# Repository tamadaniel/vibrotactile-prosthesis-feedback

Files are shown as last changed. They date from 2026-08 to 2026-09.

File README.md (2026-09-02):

# Vibrotactile Feedback Device for Transfemoral Prostheses

Open design files for a **low-cost, fully analog vibrotactile feedback add-on** for transfemoral (above-knee) prostheses. A force-sensing resistor under the heel of the prosthetic foot switches a coin vibration motor mounted on the prosthetic tube, signaling foot–ground contact to the user at every step. The device clamps onto existing prostheses — **no structural modification, no software, no microcontroller**.

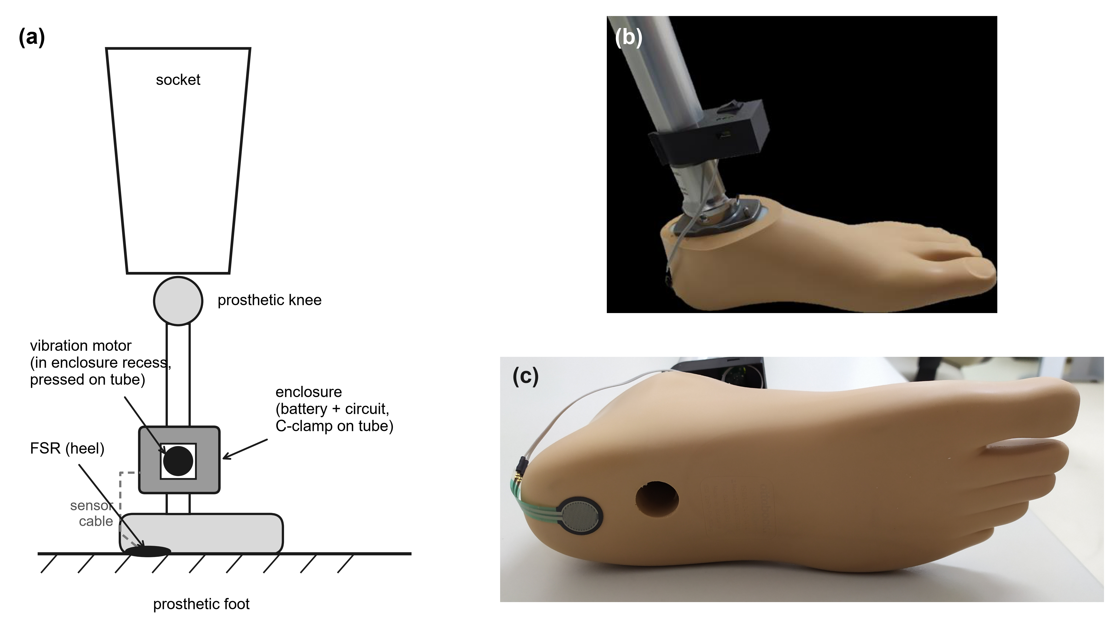
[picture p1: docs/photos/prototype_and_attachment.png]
Prototype and attachment


## How it works

Loading the heel-mounted force-sensing resistor (FSR) above an adjustable threshold drives a small-signal NPN transistor into saturation, switching the coin motor on for the loading and mid-stance period of the prosthetic limb.

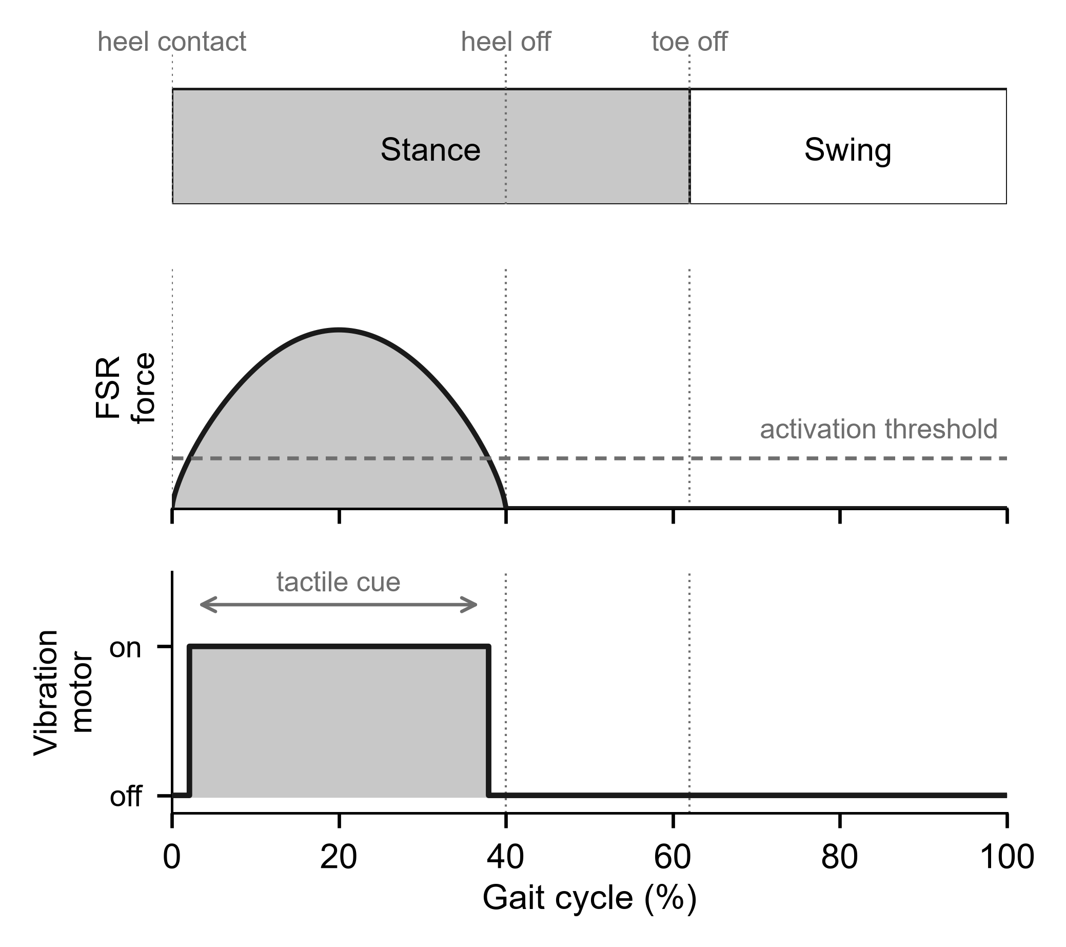
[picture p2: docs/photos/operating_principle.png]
Operating principle


Circuit (as used in the user study; reconstructed from the design files):

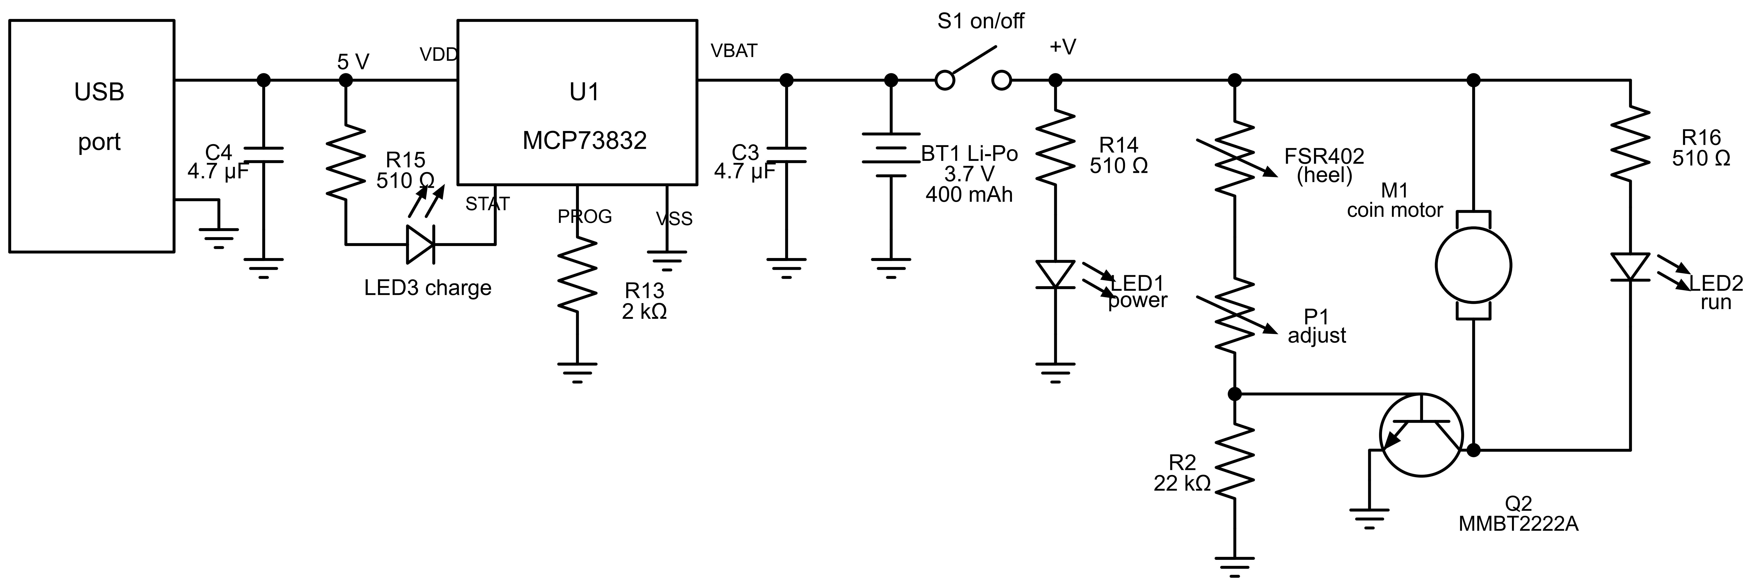
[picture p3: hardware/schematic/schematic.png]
Schematic


- **Charging:** MCP73832 constant-current/constant-voltage controller, 500 mA (set by the 2 kΩ program resistor), USB input.
- **Power:** single Li-Po cell, 3.7 V / 400 mAh; on/off switch on the battery rail; ≈50 mA total draw → ≈8 h continuous use.
- **Sensing/actuation:** FSR402 (heel) in series with an adjustment potentiometer (P1) against a fixed 22 kΩ pulldown, driving an MMBT2222A that switches the coin-type ERM motor (10 mm × 3 mm, ~150 Hz nominal). Turning P1 raises the activation threshold and can attenuate the vibration.
- **Indicators:** charge (LED3), power-on (LED1), motor activity (LED2).

## Repository contents

| Path | Contents |
|---|---|
| `hardware/pcb/` | Gerber fabrication files, BOM (with LCSC part numbers), pick-and-place, netlist, PCB layout PDF, 3D STEP of the board, EasyEDA Pro project |
| `hardware/schematic/` | Clean schematic (PNG) |
| `enclosure/` | 3D-printable housing and lid (STL + SolidWorks), K1 Max G-code, print settings |
| `bench/latency/` | Oscilloscope captures, analysis code and figure for the FSR-to-vibration delay |
| `docs/photos/` | Prototype photos, block diagram, operating principle |

## Cost

Quoted at a mainstream turnkey PCB assembly service (JLCPCB, Aug. 2026), batch of **5 assembled boards**:

| Item | 5-board batch | Per board |
|---|---|---|
| Components (9 line items) | US$ 7.10 | **< US$ 1.50** |
| PCB fabrication | US$ 4.00 | US$ 0.80 |
| Assembly, setup, stencil, fees | US$ 28.52 (incl. components) | — |
| **Total (PCB + assembly)** | **US$ 32.52** | **≈ US$ 6.50** |

Setup fees dominate at this batch size; the per-unit cost approaches the component cost at volume. Off-board parts (FSR402 sensor, coin motor, battery, switch, potentiometer, wiring) and the 3D-printed enclosure are not included in the quote. The charge-management IC (MCP73832) accounts for most of the component cost.

## Building one

1. **PCB:** upload `hardware/pcb/Gerber_*.zip`, the BOM, and the pick-and-place file to a turnkey assembly service (e.g., JLCPCB), or fabricate the board and hand-solder — all parts are mass-market components.
2. **Off-board parts:** FSR402 force-sensing resistor, C1026B-class coin ERM motor (10 × 3 mm), 3.7 V/400 mAh Li-Po cell (602525 or similar), slide switch, small potentiometer, hook-up wire.
3. **Enclosure:** print the housing and lid from `enclosure/` (PLA, 0.20 mm layers, 15% infill, no supports; ~29 min, ~14 g); the C-clamp fits the prosthetic tube by interference — no tools or screws.
4. **Mounting:** fix the FSR to the plantar surface of the prosthetic foot at the heel region (thin adhesive tape); clamp the enclosure to the distal portion of the prosthetic tube — the coin motor, seated in the enclosure recess, is pressed against the tube automatically; route the sensor cable along the prosthesis.
5. **Setup:** switch on, confirm the wearer perceives the vibration at the residual limb/socket interface, and adjust P1 so the motor activates on weight bearing at a comfortable intensity.

## Status and evidence

This is a **research prototype**. In a bench test referenced to ISO 2631-1, the vibration transmitted to the socket region measured 0.48 ± 0.06 m/s², and the delay from foot loading to vibration onset was 110 ms (95% CI 103–117 ms), reaching half amplitude at 137 ms (raw captures and analysis in [`bench/latency/`](bench/latency/)). In a cross-sectional study at IMREA HC-FMUSP (research ethics approval CAAE 75258523.9.0000.0068), ten experienced transfemoral prosthesis users wore the device during a supervised ~5-min walk: all perceived the stimulus, no device-related adverse events occurred, and all eight B-QUEST 2.0 device items reached a median score of 5/5. **No clinical outcome (gait, balance, proprioception) has been evaluated yet**; a controlled study with three-dimensional gait analysis is planned.

A preliminary account of the device concept and bench measurements appeared in:

> Tamashiro, D.S.U., Coelho, D.B., Battistella, L.R. (2025). *Development of a Proprioceptive Stimulation Device to Gait in Transfemoral Amputees.* In: XXIX Brazilian Congress on Biomedical Engineering (CBEB 2024), IFMBE Proceedings, vol. 125. Springer, Cham. https://doi.org/10.1007/978-3-031-93646-3_1

A full journal manuscript (complete technical description, bench characterization, and the user satisfaction study) is under preparation/submission; this repository accompanies it.

## Known limitations of this board revision

Review these before building or deriving from this design:

1. **USB-C CC pulldowns are absent.** Only VBUS (A9/B9) and GND (A12/B12) are connected; CC1/CC2 float and there are no 5.1 kΩ pulldowns. Consequence: the board charges normally from a USB-A→USB-C cable, but **will not receive power from USB-C→USB-C cables or USB-C (PD) chargers**. Next revision: add two 5.1 kΩ 0402 resistors, CC1→GND and CC2→GND.
2. **Charge current is 1.25C for the specified cell.** R13 = 2 kΩ programs the MCP73832 to 500 mA, above the standard 1C rating of the 400 mAh cell. Next revision: R13 = 3.3 kΩ (≈300 mA, ≈0.75C) — or keep 2 kΩ only with cells ≥500 mAh. Use only protected Li-Po cells.
3. **No flyback diode across the motor.** The inductive kick of the ERM motor at every turn-off stresses Q2 (adequate margin in practice, but repeated at every step). Next revision: a small Schottky or 1N4148 across the motor terminals.
4. **Motor overdrive.** The motor drive rail (3.7–4.2 V) slightly exceeds the motor's rated voltage (2.7–3.3 V); P1 can compensate by limiting base drive.
5. **Component availability.** The yellow 0603 LEDs (LED1/LED2) were low-stock at quoting time; any 0603 indicator LED substitutes directly. Choosing basic-library alternatives for the extended parts (headers, USB connector, LEDs) reduces the assembly fee.

## Disclaimer

This design is provided for **research and educational purposes**. It is **not an approved medical device** and must not be used for clinical decision-making or unsupervised patient care. Any use with patients must be conducted under appropriate ethical approval and professional supervision.

## License

Released under **CC BY 4.0** (see `LICENSE`). You may use, modify, and redistribute, with attribution — please cite the CBEB chapter above (see `CITATION.cff`).

## Authors

Daniel Seiei Uehara Tamashiro¹·², Gustavo Shimabukuro Marchini², Daniel Boari Coelho¹, Linamara Rizzo Battistella²
¹ Biomedical Engineering, Universidade Federal do ABC (UFABC), Brazil · ² Instituto de Medicina Física e Reabilitação, HCFMUSP, Universidade de São Paulo, Brazil

Contact: daniel.tamashiro@hc.fm.usp.br

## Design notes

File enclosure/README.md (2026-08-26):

# Enclosure (3D-printable)

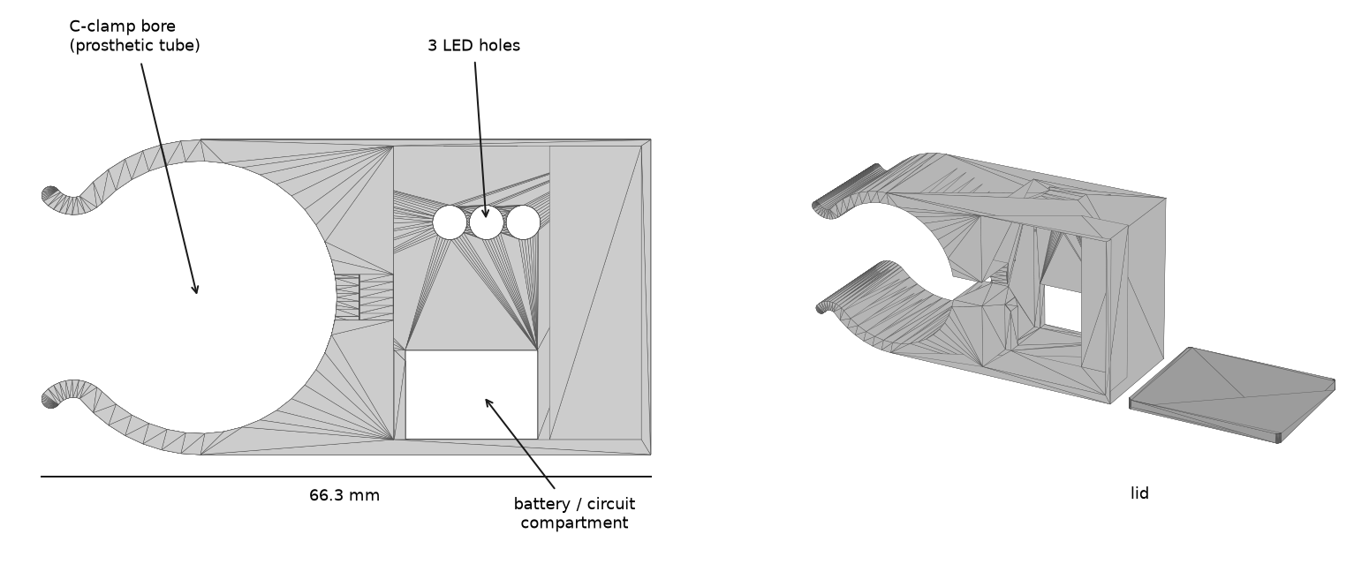
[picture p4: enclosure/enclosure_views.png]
Enclosure views


Two-part 3D-printable housing that holds the battery, the circuit board and the vibration motor, and clamps onto the distal prosthetic tube. The force-sensing resistor is **not** inside the enclosure: it is attached to the plantar surface of the prosthetic foot at the heel and connected by a thin cable.

Three features make the assembly tool-free:

- **C-shaped clamp** — snaps onto the tube by interference fit; no screws, no structural modification of the prosthesis.
- **Motor recess** — the coin motor seats in a recess facing the tube, so closing the clamp automatically presses the motor against the prosthesis. There is no separate motor mounting step, and the vibration is injected directly into the prosthesis structure.
- **Three ⌀3.75 mm holes (4 mm pitch)** on the outer face, so discrete through-hole indicator LEDs can be soldered to sit flush with the surface: charging, power-on, and motor activity stay visible with the device closed.

## Files

| File | Description |
|---|---|
| `enclosure_housing.stl` / `.SLDPRT` | main body: clamp, motor recess, LED holes, battery/circuit compartment |
| `enclosure_lid.stl` / `.SLDPRT` | closing lid |
| `gcode/housing+lid_K1Max_0.4_PLA.gcode` | both parts, ready to print on a Creality K1 Max |

## Measured dimensions (from the meshes)

| Feature | Value |
|---|---|
| Housing envelope | 66.3 × 23.0 × 34.3 mm |
| Lid | 31.8 × 26.6 × 1.9 mm |
| C-clamp bore | ⌀ ≈ 33.6 mm |
| LED holes | 3 × ⌀3.75 mm, 4 mm pitch |
| Outer face thickness at the LED holes | ≈ 2 mm |
| Filament for both parts | 4.73 m ≈ 14 g (incl. brim) |
| Tube-mounted unit (enclosure + lid + battery + circuit + motor) | 25 g |

## Print settings

Generated with Creality Print 4.3.7 for a **Creality K1 Max**, 0.4 mm nozzle:

| Parameter | Value |
|---|---|
| Filament | Generic PLA, 1.75 mm |
| Nozzle / bed temperature | 230 °C / 45 °C |
| Layer height | 0.20 mm |
| Wall line count | 2 (≈0.87 mm) |
| Top / bottom layers | 4 / 4 |
| Infill | grid, 15 % (line distance 6 mm) |
| Supports | not required |
| Bed adhesion | auto brim |
| Print speed | 250 mm/s (outer wall 210) |
| Flow ratio | 95 % |
| Both parts | ≈29 min |

Z-seam is set to *sharpest corner / hide seam*. PETG also prints this geometry (≈250 °C / 80 °C) and is the tougher option for the clamp arms, which flex on every installation.

## Printing notes

The clamp relies on the elasticity of the print for its interference fit, so orient the part such that layer lines do not run perpendicular to the clamp arms — otherwise the arms tend to delaminate when snapped onto the tube. Verify the bore against the tube you are targeting before printing a batch (the modular standard is 30 mm; the bore in this model is larger and was matched to the tube used in our prototype), and adjust the diameter in the SolidWorks part if needed.

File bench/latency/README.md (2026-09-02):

# Latency measurement: foot loading to vibration

How long the device takes to respond, from the moment the FSR is loaded to the
moment the motor is actually vibrating. This folder holds the raw oscilloscope
captures, the analysis code, and a script that reproduces the two numbers
reported in the paper.

## Result

| Instant | Definition | Mean (n = 5) | 95% CI |
|---|---|---|---|
| Onset | first sustained excursion beyond 5 SD of the pre-contact noise | 110 ms | 103–117 ms |
| Half amplitude | envelope reaches half of its steady-state value | 137 ms | 132–142 ms |

Two instants are reported because the eccentric-mass motor accelerates
progressively: the vibration builds up over tens of milliseconds instead of
starting abruptly, so any single number depends on the threshold chosen.
`tempos_criterio.pdf` makes that dependence visible — it plots the piezo
envelope for all five captures with the 3, 5 and 10 σ criteria marked, and the
three land at visibly different points on the same rise.

Almost all of this delay is mechanical, not electronic. The analog circuit
switches the motor within microseconds; the rest is the motor spinning up.
Shortening it would require a faster actuator, such as a linear resonant
actuator, not a redesign of the circuit.

## Setup

Two-channel oscilloscope (PicoScope 2204A, 6.1 kHz per channel) recording
simultaneously:

- **Channel A** — the FSR, which steps from about 3.75 V to about 3.02 V when
  loaded.
- **Channel B** — a piezoelectric element on the motor housing, picking up the
  vibration itself rather than the drive signal.

## Two corrections the raw cursor readings do not make

The manual cursor readings in `tempo.xlsx` (mean 93.8 ms over 10 trials)
**understate** the delay, for two reasons that the analysis code handles:

1. **The oscilloscope trigger is not the FSR step.** The scope fired 2.2 to
   6.8 ms *after* the step had already begun, so taking t = 0 as the start
   loses those milliseconds. `degrau_fsr()` locates the real step by its
   mid-level crossing, which is immune both to the transition spreading across
   two or three samples and to noise spikes of up to 0.18 V.
2. **The piezo has no clean edge.** Its amplitude grows slowly, so the instant
   read off the screen depends entirely on where the eye places the threshold.
   The code reports several thresholds instead of one, so the sensitivity is
   visible rather than hidden.

All timing here is therefore referenced to the FSR step itself, not to the
oscilloscope trigger.

## Data

Ten captures were taken. **Five contain complete waveforms** (`med3`, `med7`,
`med8`, `med9`, `med10`) and are the five kept here and analysed; the other
five held only acquisition metadata, with no waveform to measure, and are not
included.

- `*_med*.csv` — raw captures, semicolon-separated, comma decimal, latin-1.
  Columns: time (ms), channel A (V), channel B (mV).
- `*_med*.png` — PicoScope screenshots of the same captures.
- `tempo.xlsx` still lists all ten trials, since the manual cursor readings
  were taken on screen before the discard.

## Code

Requires `numpy`, `pandas`, `scipy`, `matplotlib`, `openpyxl`.

```bash
python reproduce_paper_values.py   # the two numbers in the paper, with CIs
python analisa_tempos.py           # full per-trial table, 3/5/10 sigma
python figura_tempos.py            # regenerates tempos_criterio.pdf/.png
```

`reproduce_paper_values.py` is the entry point if you only want to check the
published values. `analisa_tempos.py` is the original analysis, kept verbatim
except that its report was moved inside a `__main__` guard so it can be
imported quietly; its comments are in Portuguese. The half-amplitude instant is
computed in `reproduce_paper_values.py`, which states its envelope definition
explicitly, since that number depends on it.

## Limitation

Five valid captures is a small sample, and the measurement was made on the
bench with the FSR pressed by hand, not under a walking load. Absolute timing
under gait may differ.

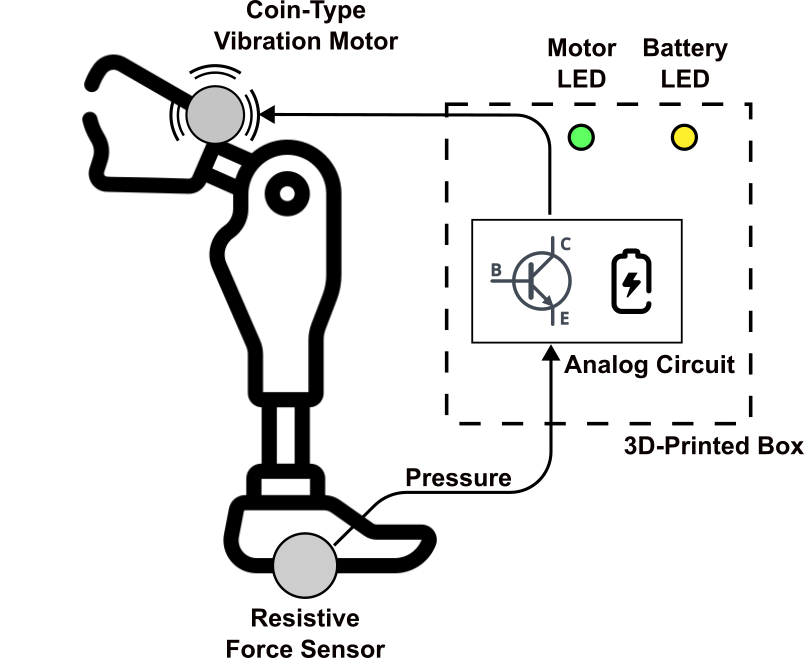
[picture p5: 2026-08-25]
docs/photos/block_diagram.png

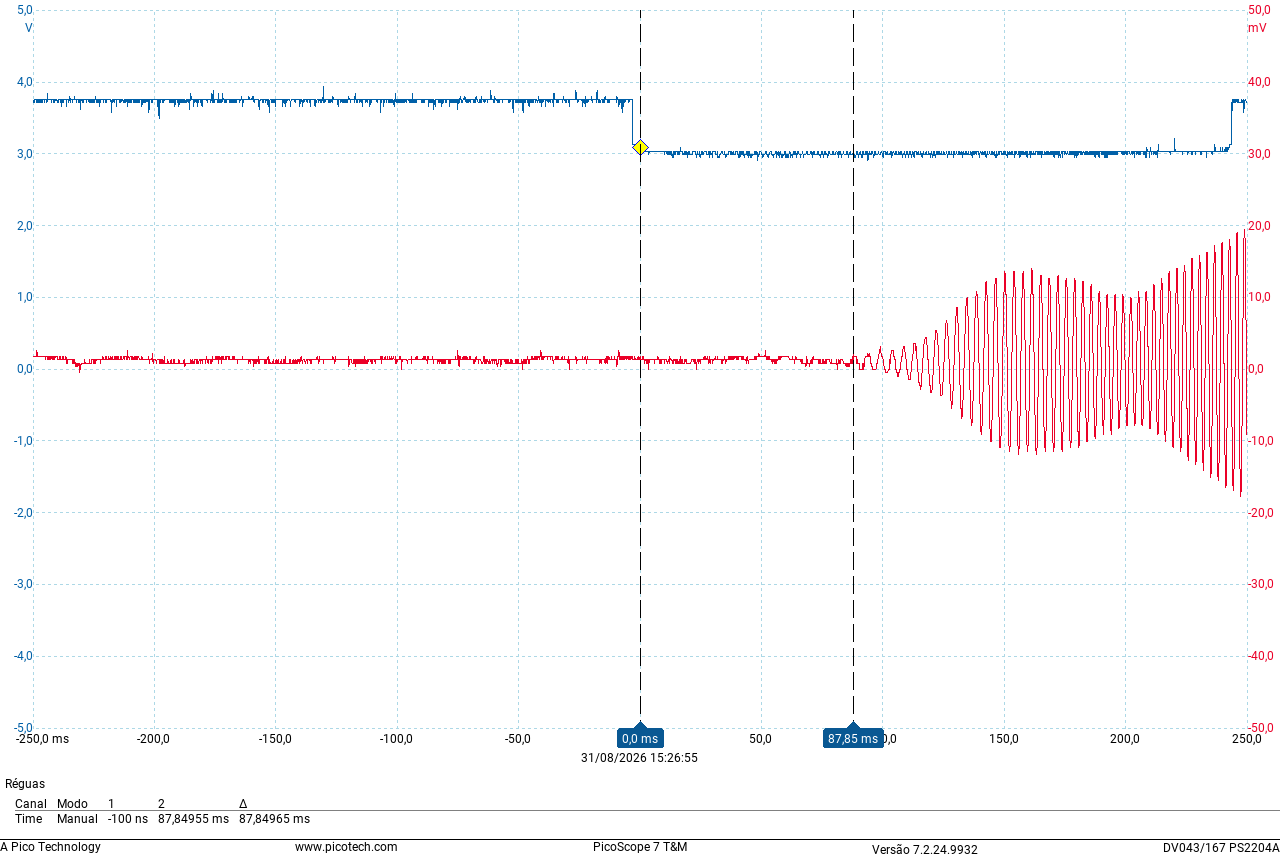
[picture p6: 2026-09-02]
bench/latency/20260831-0002_joelho-0002_med3.png

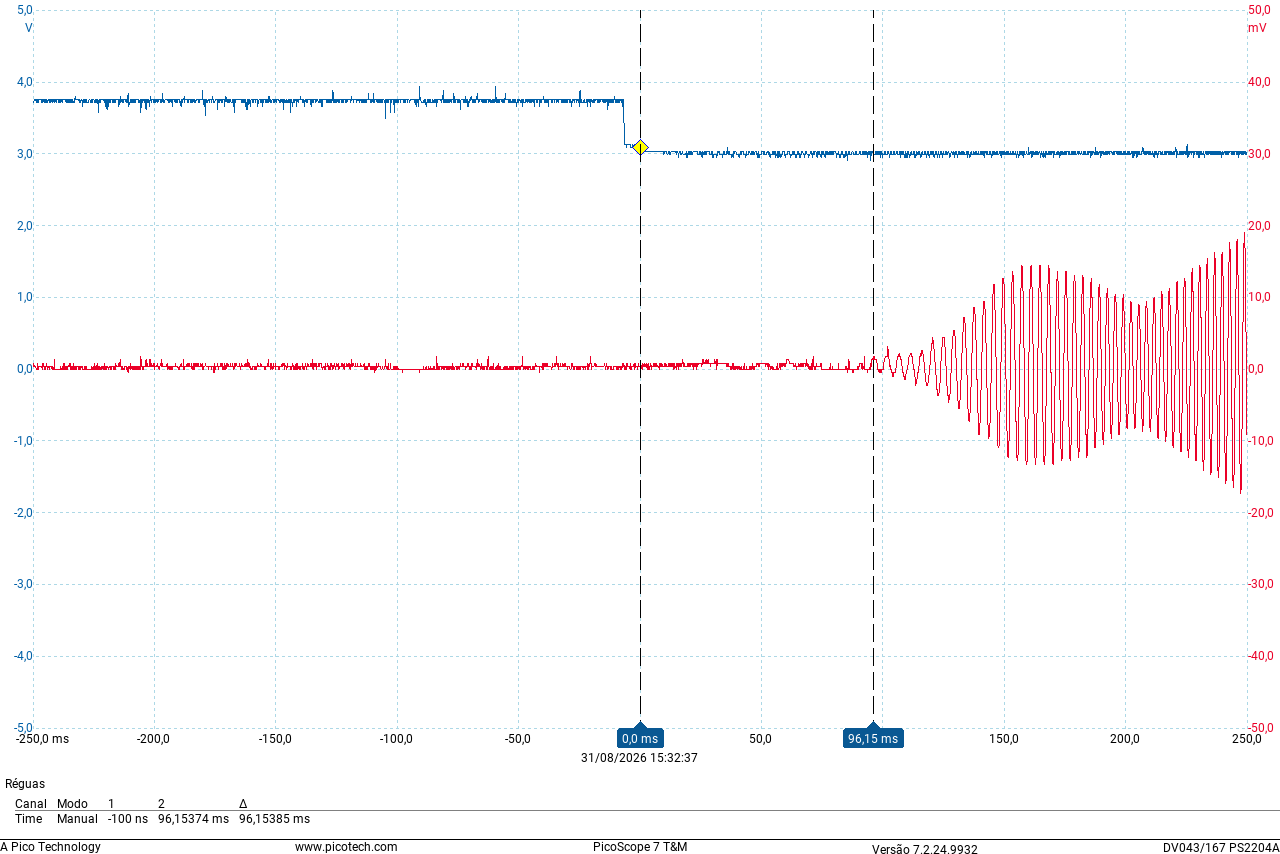
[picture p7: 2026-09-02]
bench/latency/20260831-0002_joelho-0002_med7.png

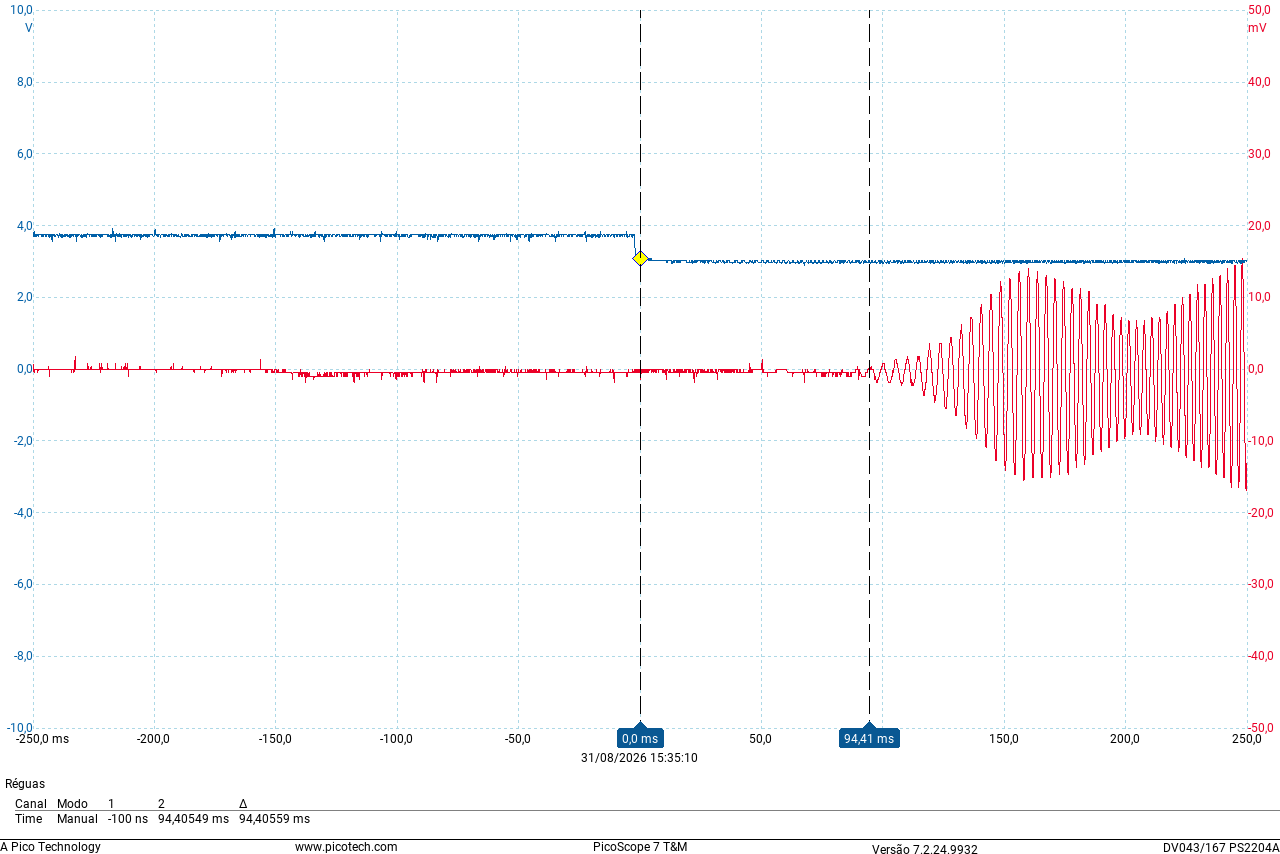
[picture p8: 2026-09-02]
bench/latency/20260831-0002_joelho-0002_med10.png

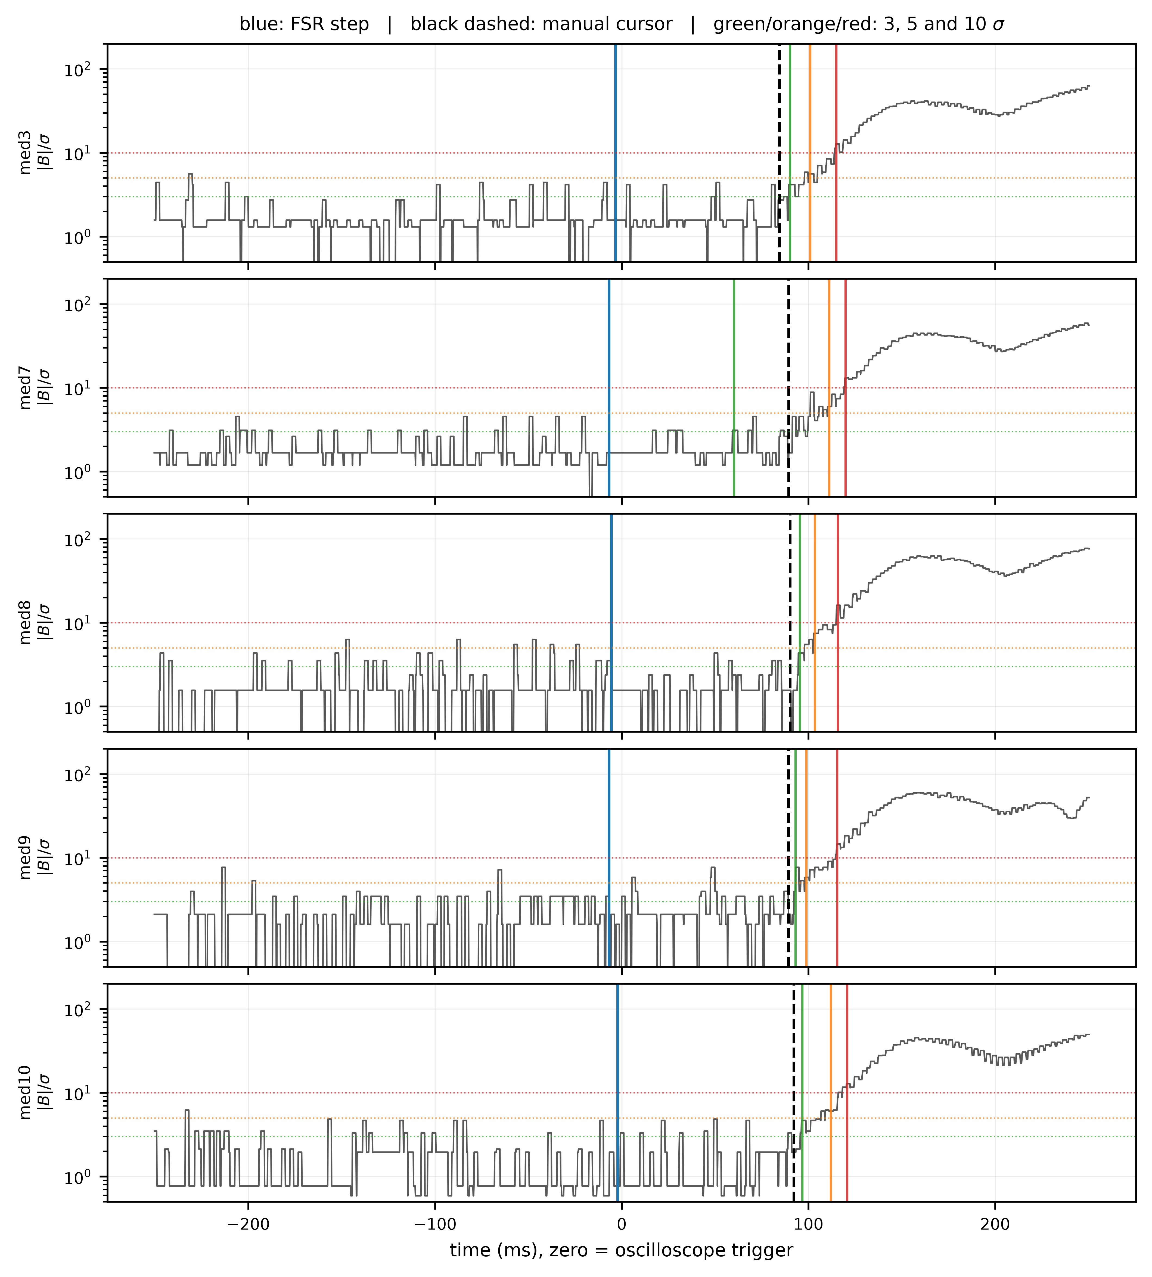
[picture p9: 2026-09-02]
bench/latency/tempos_criterio.png

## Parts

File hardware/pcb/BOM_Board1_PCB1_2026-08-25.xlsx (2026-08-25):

No. | Quantity | Comment | Designator | Footprint | Value | Manufacturer Part | Manufacturer | Supplier Part | Supplier
1 | 2 | 4.7uF | C3,C4 | C0402 | 4.7uF | CL05A475MP5NRNC | SAMSUNG(三星) | C23733 | LCSC
2 | 5 | PZ254V-11-02P | H1,H2,H3,H4,H5 | HDR-TH_2P-P2.54-V-M |  | PZ254V-11-02P | XFCN(兴飞) | C492401 | LCSC
3 | 2 | 19-213/Y2C-CQ2R2L/3T(CY) | LED1,LED2 | LED0603-RD-YELLOW |  | 19-213/Y2C-CQ2R2L/3T(CY) | EVERLIGHT(亿光) | C72038 | LCSC
4 | 1 | KT-0603R | LED3 | LED0603-RD |  | KT-0603R | KENTO | C2286 | LCSC
5 | 1 | MMBT2222A 1P | Q2 | SOT-23-3_L2.9-W1.3-P1.90-LS2.4-BR |  | MMBT2222A 1P | CJ(江苏长电/长晶) | C8512 | LCSC
6 | 1 | 22kΩ | R2 | R0402 | 22kΩ | 0402WGF2202TCE | UNI-ROYAL(厚声) | C25768 | LCSC
7 | 1 | 2kΩ | R13 | R0402 | 2kΩ | 0402WGF2001TCE | UNI-ROYAL(厚声) | C4109 | LCSC
8 | 3 | 510Ω | R14,R15,R16 | R0402 | 510Ω | 0402WGF5100TCE | UNI-ROYAL(厚声) | C25123 | LCSC
9 | 1 | MCP73832T-2DCI/OT | U1 | SOT-23-5_L2.9-W1.6-P0.95-LS2.8-BR |  | MCP73832T-2DCI/OT | MICROCHIP(美国微芯) | C625601 | LCSC
10 | 1 | TYPE-C 6P | USB1 | TYPE-C-SMD_TYPE-C-6P |  | TYPE-C 6P | SHOU HAN(首韩) | C456012 | LCSC

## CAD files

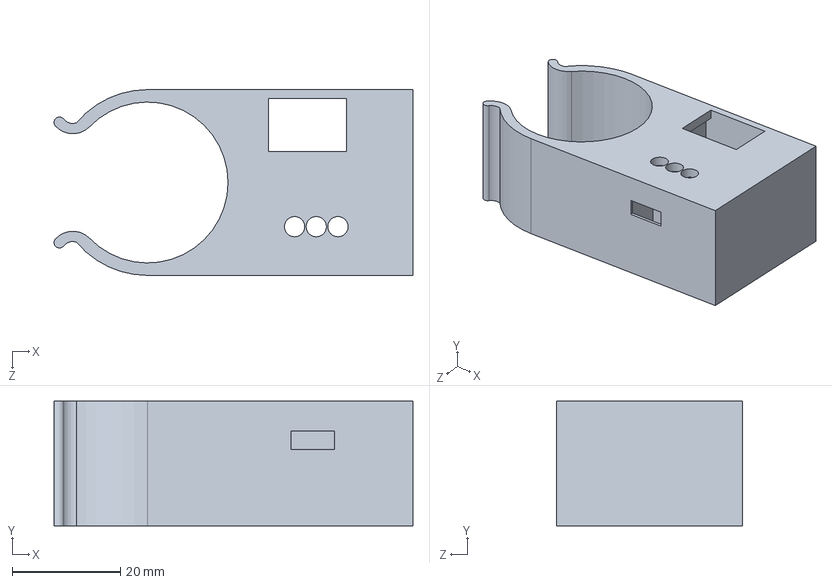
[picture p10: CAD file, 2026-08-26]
enclosure/enclosure_housing.SLDPRT
66.3 x 23.0 x 34.3 mm

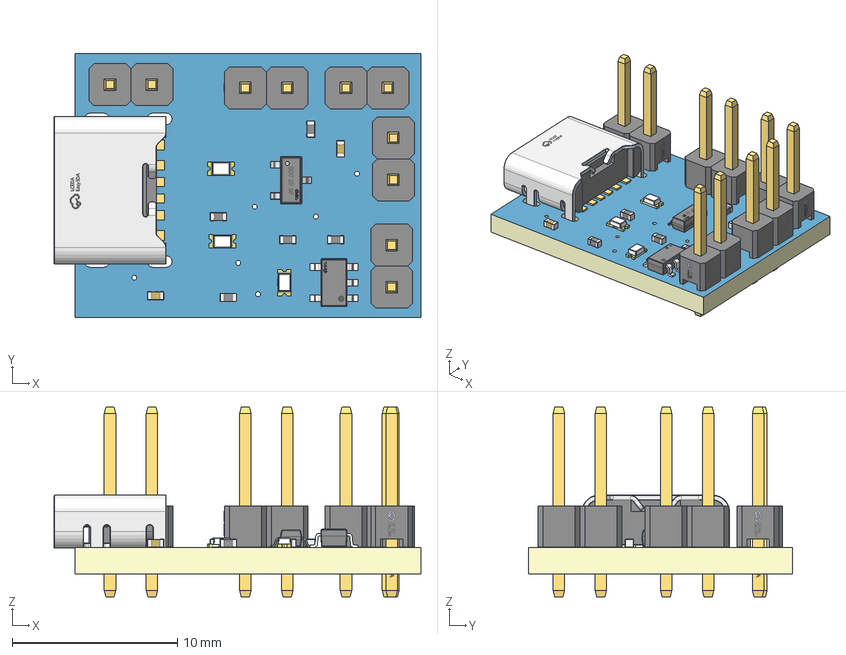
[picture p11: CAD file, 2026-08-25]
hardware/pcb/3D_PCB1_2026-08-25.step
22.2 x 16.0 x 11.5 mm
Board~9DXw
TopCopper~9DXw
BottomCopper~9DXw
TopSilkscreen~9DXw
BottomSilkscreen~9DXw
TopFpcStiffener~9DXw
BottomFpcStiffener~9DXw
SOT-23-5_L2.9-W1.6-P0.95-LS2.8-BR~SOT-23-5_L2.9-W1.6-P0.95-LS2.8-BR~jfYT
R0402~R0402_L1.0-W0.5-H0.5~DUJP x 5
SOT-23-3_L2.9-W1.3-P1.90-LS2.4-BR~SOT-23-3P_L2.9-W1.3-H1.0-LS2.4-P0.95~AkXh
C0402~C0402_L1.0-W0.5-H0.5~BuJX x 2
LED0603-RD~LED0603-RD~3gzQ
HDR-TH_2P-P2.54-V-M~HDR2.54-M-LI-1X2P~mG0G x 5
LED0603-RD-YELLOW~LED0603-RD-YELLOW~NeA1 x 2
TYPE-C-SMD_TYPE-C-6P~TYPE-C-SMD_6P-L8.9-W6.8-H3.2-P1.00~N0o2

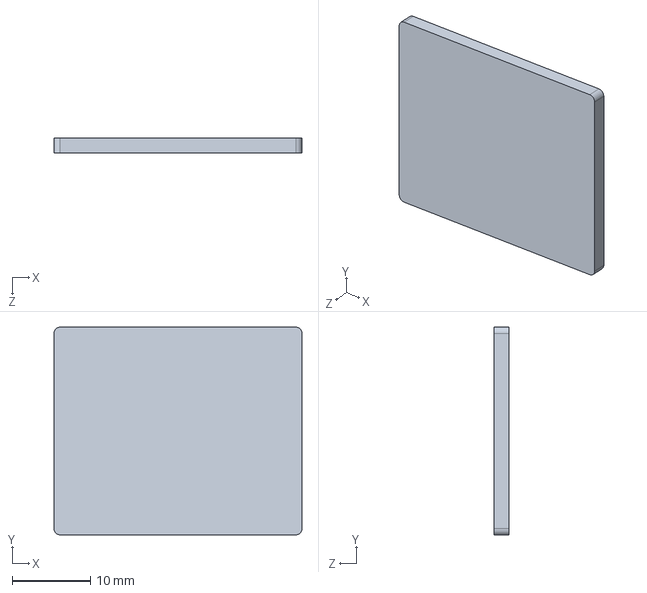
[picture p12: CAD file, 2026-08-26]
enclosure/enclosure_lid.SLDPRT
31.8 x 26.6 x 1.90 mm

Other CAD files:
enclosure/enclosure_housing.stl
enclosure/enclosure_lid.stl

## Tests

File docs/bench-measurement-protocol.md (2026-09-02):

# Bench measurement protocol (frequency, voltage, latency)

> **Latency (§3) has since been measured** — 110 ms to onset, 137 ms to half amplitude. The captures, analysis and figure are in [`bench/latency/`](../bench/latency/); §3 below is kept as the procedure that was followed. Frequency (§1) and motor voltage (§2) remain open.

Simple procedures to characterize the quantities that the current publication reports as "not measured". None of them requires certified/calibrated instrumentation: frequency and latency depend only on the instrument's crystal time base, and voltage needs an ordinary multimeter. Report instrument models and the method; traceable calibration is only required in regulatory/compliance contexts, not for research characterization.

## 1. Vibration frequency at operating voltage

**Recommended: piezo disc + oscilloscope.** Tape a piezoelectric buzzer disc to the prosthetic tube near the motor and connect it directly to one scope channel. Run the motor from the battery rail (as in the device). The period of the displayed oscillation is the mechanical vibration frequency at the actual mounting point. Read at full charge (4.2 V) and near-empty (≈3.5 V).

*Alternative (zero cost):* record the motor tone with a smartphone **microphone** spectrum-analyzer app (48 kHz sampling); the fundamental peak is the rotation frequency. Do **not** use the phone's accelerometer (100–400 Hz sampling — below Nyquist for a ~150–200 Hz signal).

*Cross-check (electrical):* commutation ripple across the motor terminals or a 1 Ω series resistor; rotation frequency = ripple frequency ÷ number of commutator segments (typically 3).

## 2. Motor terminal voltage

Multimeter across the motor terminals while running, at full and near-empty battery. Report the range (battery rail minus the transistor saturation drop).

## 3. Sensor-to-vibration latency

Two-channel oscilloscope, single-trigger:
- CH1 on the transistor collector (electrical switching instant);
- CH2 on the piezo disc on the tube (first mechanical oscillation).

Press the FSR; measure the interval from the collector edge to the first oscillation exceeding a small threshold. Repeat 10 times; report the median and range. This captures the full electromechanical spin-up latency of the ERM motor as mounted.

**As executed:** a PicoScope 2204A recorded the FSR step directly (rather than the collector edge) on CH1 and a piezo element on the motor housing on CH2. Timing was referenced to the FSR step located by its mid-level crossing, because the scope trigger fired 2–7 ms after the step began. Five of ten captures contained complete waveforms. Because the ERM builds up gradually, two instants are reported instead of one: see [`bench/latency/`](../bench/latency/).

## Suggested reporting sentence

> "Vibration frequency at the operating voltage was measured with a piezoelectric disc coupled to the prosthetic tube and a digital oscilloscope (<model>): f = XX Hz at 4.0 V."

The latency sentence is no longer a template; the measured wording is in the manuscript and in [`bench/latency/README.md`](../bench/latency/README.md).

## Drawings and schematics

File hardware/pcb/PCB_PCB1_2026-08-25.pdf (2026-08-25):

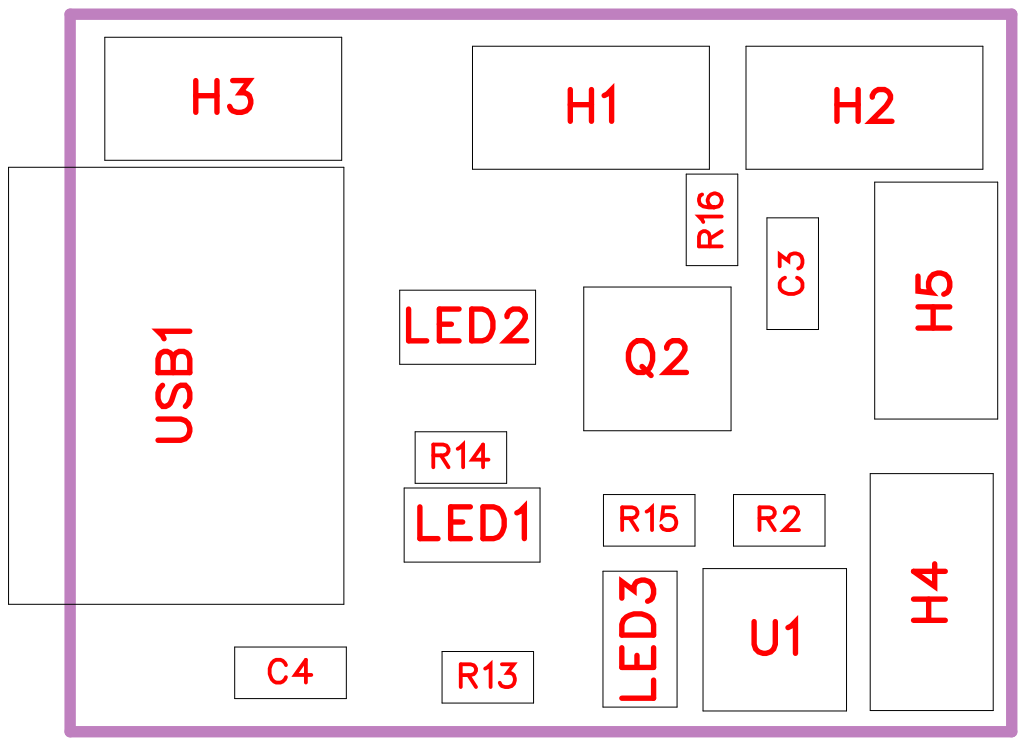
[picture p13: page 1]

No. | Quantity | Comment | Designator | Footprint | Value | Manufacturer Part | Manufacturer | Supplier Part | Supplier
1 | 2 | 4.7uF | C3,C4 | C0402 | 4.7uF | CL05A475M P5NRNC | SAMSUNG( ) 三星 | C23733 | LCSC
2 | 5 | PZ254V-11-0 2P | H1,H2,H3,H4,H5 | HDR-TH_2P-P2.54-V-M | | PZ254V-11-0 2P | XFCN(兴飞 ) | C492401 | LCSC
3 | 2 | 19-213/Y2C-CQ2R2L/3T( CY) | LED1,LED2 | LED0603-RD -YELLOW | | 19-213/Y2C-CQ2R2L/3T( CY) | EVERLIGHT( 亿光 ) | C72038 | LCSC
4 | 1 | KT-0603R | LED3 | LED0603-RD | | KT-0603R | KENTO | C2286 | LCSC
5 | 1 | MMBT2222A 1P | Q2 | SOT-23-3_L2 .9-W1.3-P1.9 0-LS2.4-BR | | MMBT2222A 1P | CJ(江苏长电 / 长晶 ) | C8512 | LCSC
6 | 1 | 22k | R2 | R0402 | 22k | 0402WGF22 02TCE | UNI-ROYAL( 厚声 ) | C25768 | LCSC
7 | 1 | 2k | R13 | R0402 | 2k | 0402WGF20 01TCE | UNI-ROYAL( ) 厚声 | C4109 | LCSC
8 | 3 | 510 | R14,R15,R16 | R0402 | 510 | 0402WGF51 00TCE | UNI-ROYAL( ) 厚声 | C25123 | LCSC
9 | 1 | MCP73832T-2DCI/OT | U1 | SOT-23-5_L2 .9-W1.6-P0.9 5-LS2.8-BR | | MCP73832T-2DCI/OT | MICROCHIP( 美国微芯 ) | C625601 | LCSC
10 | 1 | TYPE-C 6P | USB1 | TYPE-C-SM D_TYPE-C-6 P | | TYPE-C 6P | SHOU HAN(首韩 ) | C456012 | LCSC

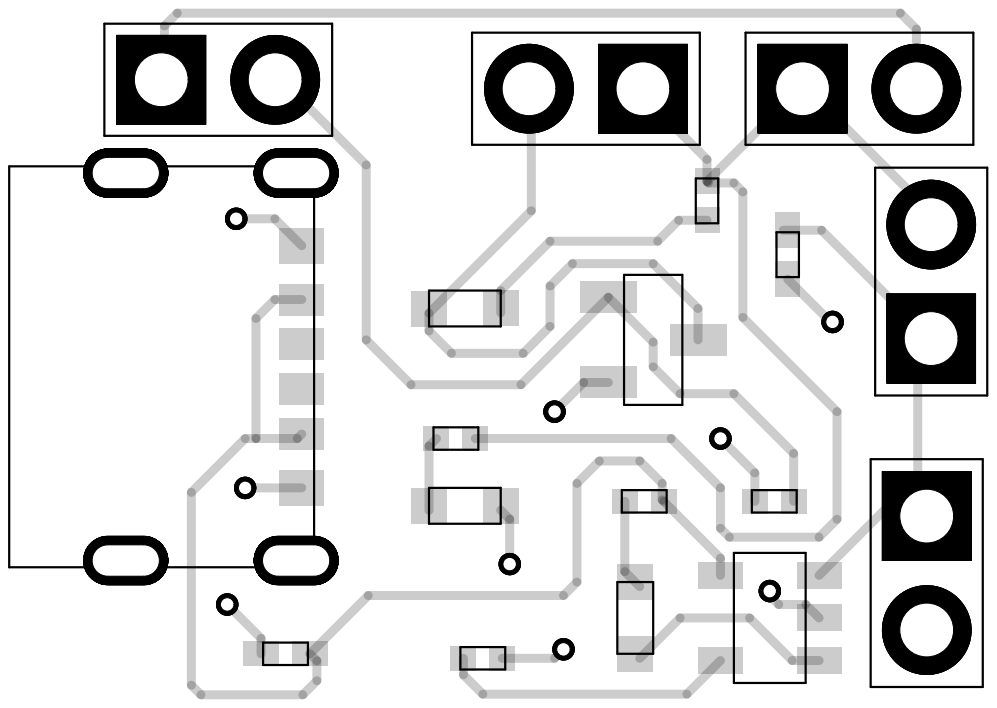
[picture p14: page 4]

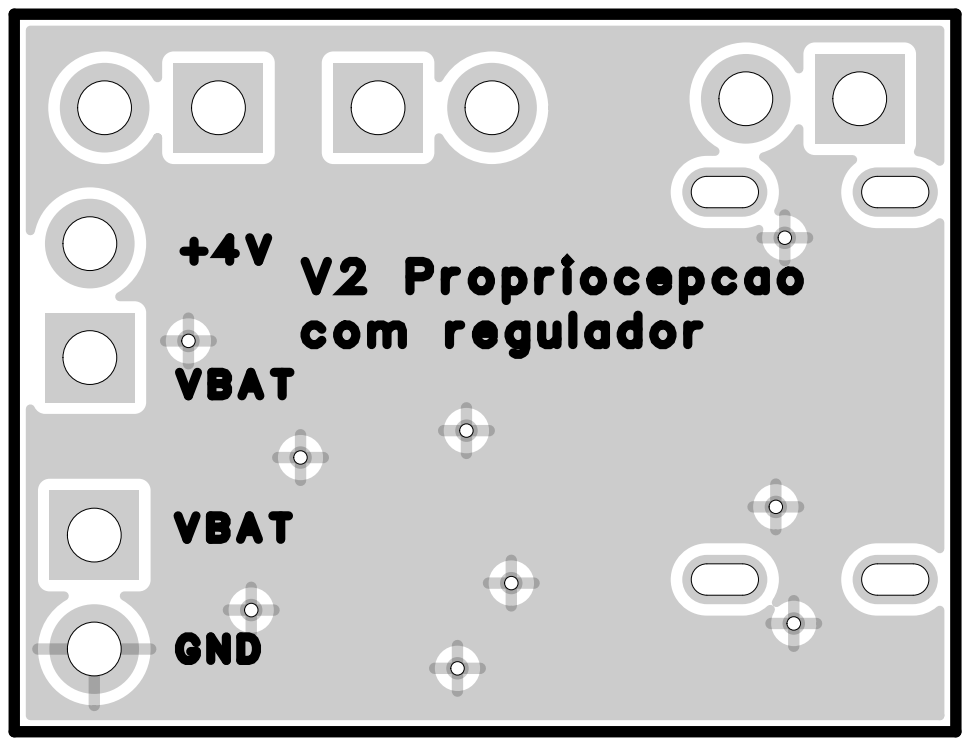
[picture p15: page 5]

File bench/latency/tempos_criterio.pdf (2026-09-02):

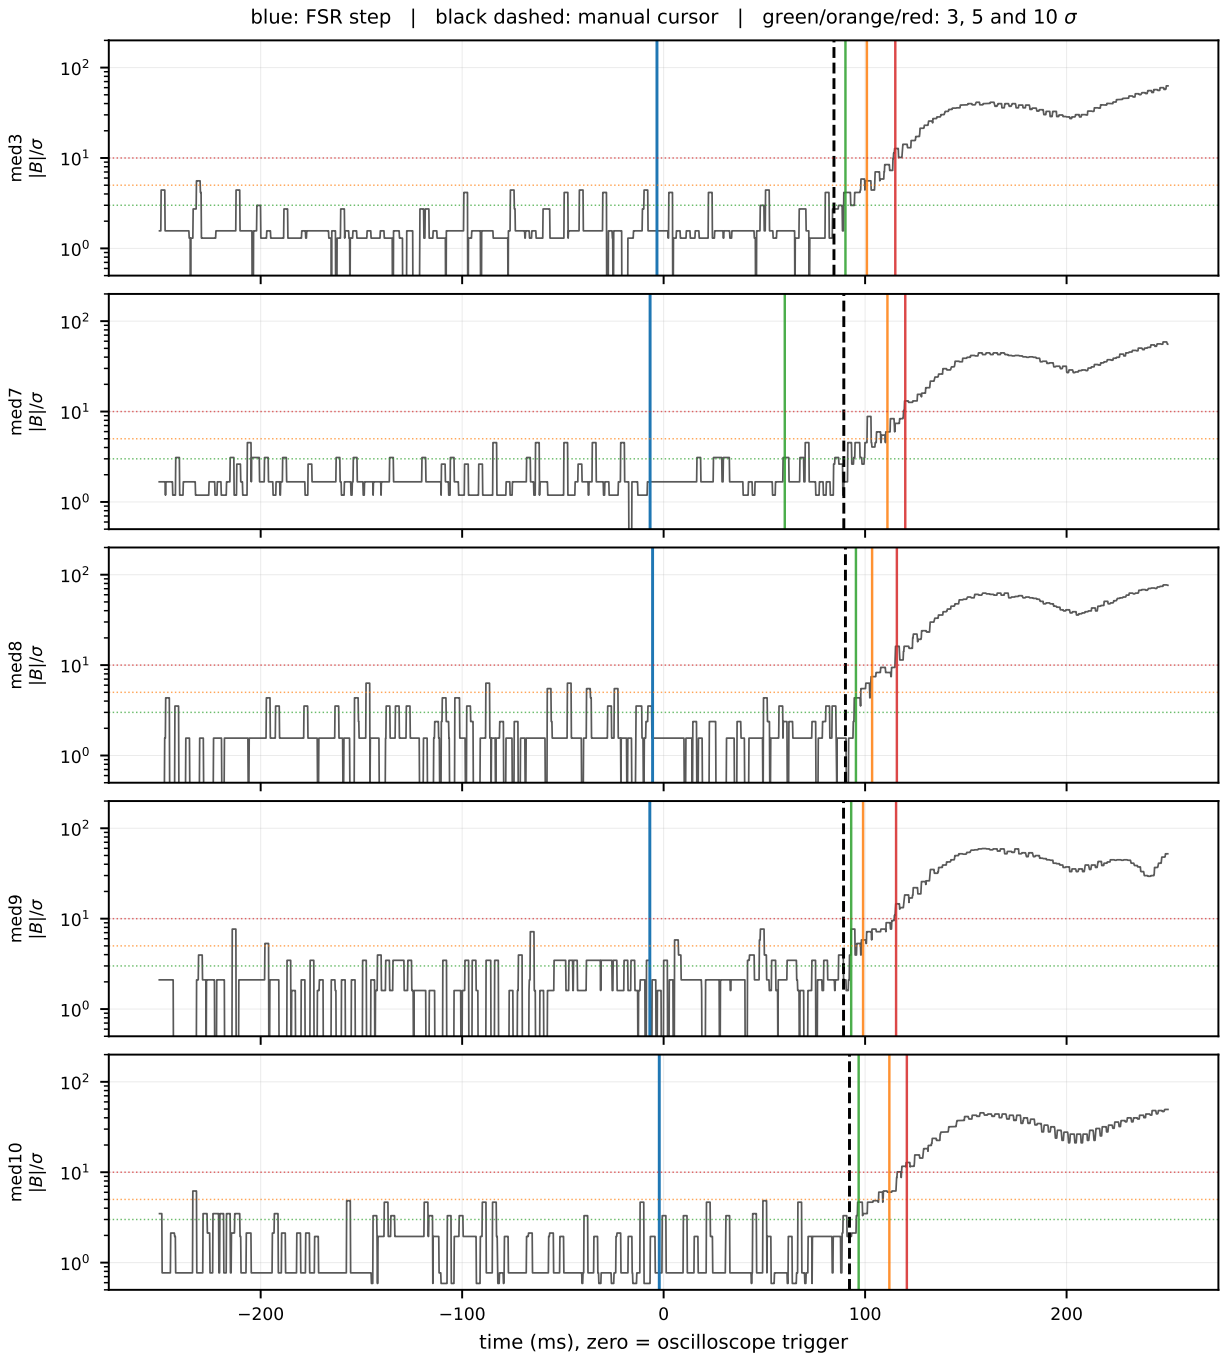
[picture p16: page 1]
med3 |B|/σ; med7 |B|/σ; med8 |B|/σ; med9 |B|/σ; med10

blue: FSR step | black dashed: manual cursor | green/orange/red: 3, 5 and 10 σ

time (ms), zero = oscilloscope trigger

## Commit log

2026-08-25 Open design files: PCB (Gerber, BOM, pick-and-place), schematic, photos, docs
    Low-cost analog vibrotactile feedback add-on for transfemoral prostheses.
    Accompanies the CBEB 2024 chapter (doi:10.1007/978-3-031-93646-3_1) and the
    journal manuscript in preparation.
    [3D_PCB1_2026-08-25.step, BOM_Board1_PCB1_2026-08-25.xlsx, PickAndPlace_PCB1_2026_08_25.xlsx]
2026-08-25 README: document known limitations of this board revision (USB-C CC pulldowns, charge rate, flyback diode)
2026-08-26 docs: bench protocol for frequency, terminal voltage, and latency measurements
2026-08-26 Motor seats in enclosure recess, pressed on tube by the clamp (per author)
2026-08-26 Add 3D-printable enclosure (STL + SolidWorks), measured specs, and views
    [enclosure_v6.SLDPRT, enclosure_v6.stl]
2026-08-26 Enclosure: two-part design (housing + lid), K1 Max G-code and print settings
    [enclosure_housing.SLDPRT, enclosure_housing.stl, enclosure_lid.SLDPRT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]
2026-08-26 Enclosure: add PLA print profile (as used in the study) alongside PETG
2026-08-26 Enclosure: corrected PLA profile (0.20 mm, 15% infill, no supports); 25 g tube-mounted unit; sensor mounts on the foot
2026-08-26 README: enclosure files now published; add print summary to build steps
2026-09-02 Add FSR-to-vibration latency measurement
    The delay from foot loading to vibration was measured on the bench with a
    two-channel oscilloscope but had not been published. Adds the raw captures,
    the analysis code, and the figure.
    Result: onset at 110 ms (95% CI 103-117), half amplitude at 137 ms
    (95% CI 132-142), over the five captures containing complete waveforms.
    Almost all of it is the ERM motor spinning up, not the circuit.
    Timing is referenced to the FSR step located by its mid-level crossing,
    not to the oscilloscope trigger, which fired 2-7 ms after the step began;
    the manual cursor readings in tempo.xlsx understate the delay for that
    reason and are kept only for comparison.
    reproduce_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
    [20260831-0002_joelho-0002_med1.csv, 20260831-0002_joelho-0002_med10.csv, 20260831-0002_joelho-0002_med2.csv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]
2026-09-02 Keep only the five captures with usable waveforms
    The five metadata-only files had no waveform to measure and were only
    documenting their own absence. The README still records that ten captures
    were taken and why five were dropped.
    [20260831-0002_joelho-0002_med1.csv, 20260831-0002_joelho-0002_med2.csv, 20260831-0002_joelho-0002_med4.csv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]
